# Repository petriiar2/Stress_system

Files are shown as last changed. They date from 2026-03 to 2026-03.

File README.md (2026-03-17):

# Physiological Monitoring System - Hardware Design & Sensor Integration

> **PCC1 Project | KTH Royal Institute of Technology | MSc Medical Engineering | Stockholm, 2026**  
> *This repository covers only the hardware design, sensor selection, wiring, and embedded firmware — the physical core of the system.*
> *Other aspects of the project ( software component , website ) not considered in this repository*

---

## Table of Contents

1. [Project Overview](#1-project-overview)
2. [System Architecture](#2-system-architecture)
3. [Internal Station — Patient Side](#3-internal-station--patient-side)
4. [External Station — Dentist Side](#4-external-station--dentist-side)
5. [Sensor Reference](#5-sensor-reference)
   - [Pressure Sensor](#51-pressure-sensor--abpdrrv060mgaa5)
   - [GSR Sensor](#52-gsr-sensor--galvanic-skin-response)
   - [Moisture Sensor](#53-moisture-sensor--adafruit-stemma)
   - [PPG Sensor](#54-ppg-sensor--max30102)
6. [Microcontrollers & Communication](#6-microcontrollers--communication)
7. [Power Supply](#7-power-supply)
8. [PCB](#8-pcb--enclosure)
9. [Current Limitations & Future Work](#9-current-limitations--future-work)
10. [Authorship & Contributions](#10-authorship--contributions)

---

## 1. Project Overview

Dental patients cannot speak during procedures. The traditional workaround — raising a hand to signal pain — forces dentists to split their attention between precise work under magnifying loupes and watching for a hand signal outside their field of view. It is also binary: the signal says *stop*, but conveys nothing about intensity or rising discomfort.

**BM-Dentist** is a Bluetooth-enabled physiological monitoring system that gives patients a richer, low-effort communication channel while providing dentists with objective, real-time data about patient comfort:

- A **squeeze ball** lets the patient signal pain by squeezing harder or with squeeze patterns (1 squeeze = mild, 2 = moderate, 3+ = severe).
- **Involuntary physiological sensors** (GSR + skin moisture) detect stress independently of the patient's conscious action — catching anxiety before it reaches the threshold of deliberate signalling.
- **LED ring indicators** on the dentist's side are positioned within their natural visual field and communicate pain and stress levels through colour and intensity without requiring the dentist to look away.
- A **web dashboard** logs all signals in real time and generates post-procedure statistics for quality improvement.

The system is designed as a prototype towards clinical use — not yet a certified medical device.

---

## 2. System Architecture

The system consists of three interconnected subsystems:

```
┌──────────────────────────────┐        BLE 5.0         ┌──────────────────────────────────────┐
│     INTERNAL STATION         │ ────────────────────►  │         EXTERNAL STATION             │
│        (Patient Side)        │                        │          (Dentist Side)              │
│                              │                        │                                      │
│  Pressure Sensor             │                        │  nRF52840 #1  ──UART──  nRF52840 #2  │
│  GSR Sensor                  │  XIAO nRF52840         │  LED Pain Ring          OLED Display │
│  Moisture Sensor             │  (BLE Peripheral)      │  LED Stress Ring        Buttons      │
│  MAX30102 (PPG)              │                        │  (BLE Central)          (BLE→USB)    │
│                              │                        │                                      │
└──────────────────────────────┘                        └──────────────┬───────────────────────┘
                                                                       │ USB Serial
                                                              ┌────────▼────────┐
                                                              │   WEB APP       │
                                                              │  (HTML/JS)      │
                                                              │  Real-time plot │
                                                              │  Post-proc stats│
                                                              └─────────────────┘
```

**Data flow summary:**

1. Sensors → Internal XIAO nRF52840 via analog ADC / I²C
2. Internal nRF → External nRF #1 via BLE UART (20 Hz)
3. External nRF #1 → LED rings (pain & stress visualisation) + External nRF #2 via UART
4. External nRF #2 → Computer via USB Serial → Web app

The web/software layer (dashboard, statistical analysis, CSV export) was developed by other team members and is referenced here for context only.

---

## 3. Internal Station — Patient Side

The internal station is the patient-held device. It houses all sensors, the microcontroller, and the BLE radio inside a custom 3D-printed enclosure designed for comfortable grip. Sensors that must contact the patient's skin (electrodes, moisture pad) exit the enclosure via JST connectors and are attached externally.

<p align="center">
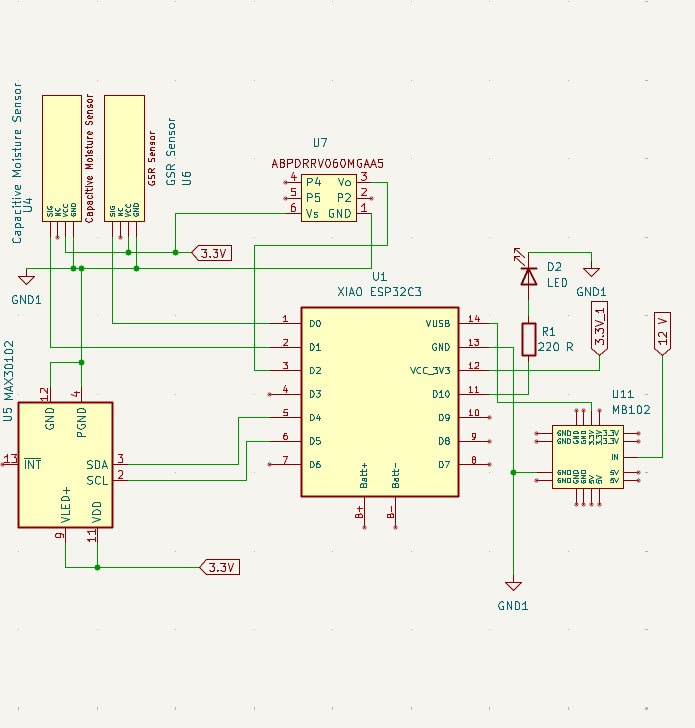
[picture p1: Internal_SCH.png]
  
  &nbsp;
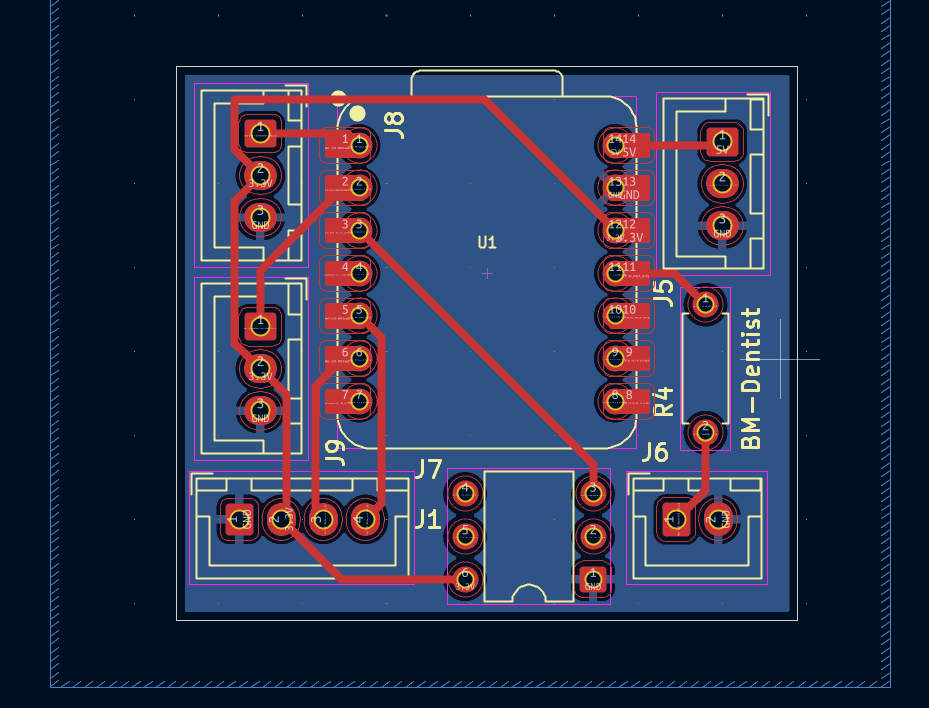
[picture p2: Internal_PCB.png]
  
</p>

<p align="center">
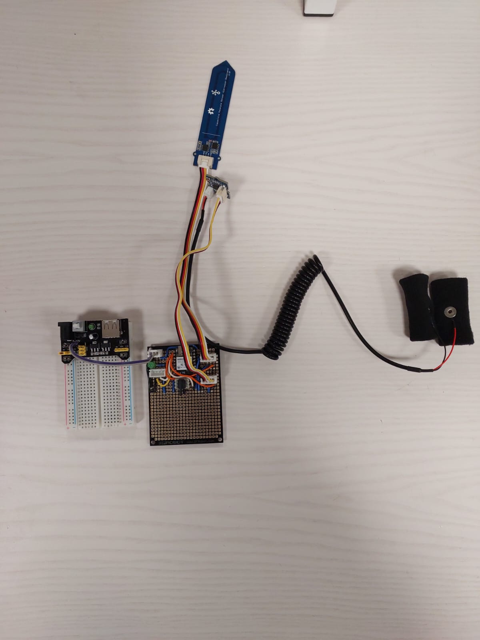
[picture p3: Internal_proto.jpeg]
  
</p>

### What it does

- Reads all four sensors at **20 Hz** via a continuous polling loop
- Packages readings into a CSV string: `pressure,gsr,moisture\n`
- Transmits over **BLE UART** to the external station
- Performs **min-max normalisation** against individually calibrated baseline values
- Drives a **status LED** (pin D10) to confirm active transmission

### Calibration

Before a procedure, a 5-second calibration sequence is triggered from the dentist side:

| Phase | Patient action | What is recorded |
|---|---|---|
| Resting | Hold balloon without squeezing | `P_min` — baseline pressure |
| Max squeeze | Squeeze as hard as possible | `P_max` — individual squeeze ceiling |
| Resting (continuous) | Stay relaxed | `GSR_baseline` — calm-state conductance average |

Subsequent readings are normalised as:

```
pressure_norm = (P_current - P_min) / (P_max - P_min)
stress_norm   = |GSR_current - GSR_baseline| / GSR_range
```

Patient gender and age category are also collected at calibration time (they affect pain thresholds), though in the current prototype the demographic adjustment coefficients are set to neutral (A=1.0, B=0.0) pending clinical data.

---

## 4. External Station — Dentist Side

The dentist-side station receives data wirelessly and translates it into immediate visual feedback — no screen-watching required.

<p align="center">
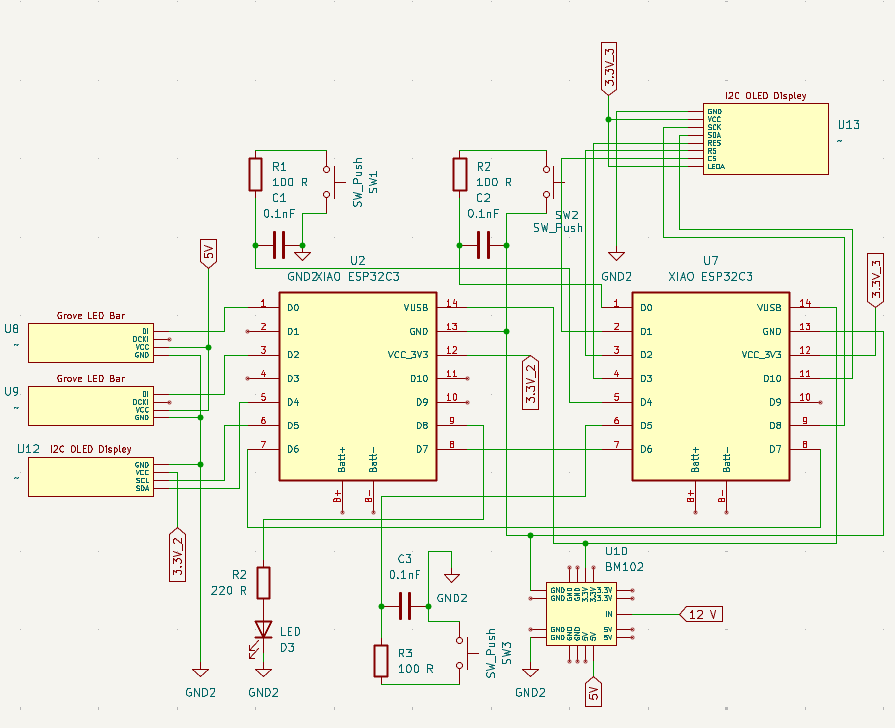
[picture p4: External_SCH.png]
  
  &nbsp;
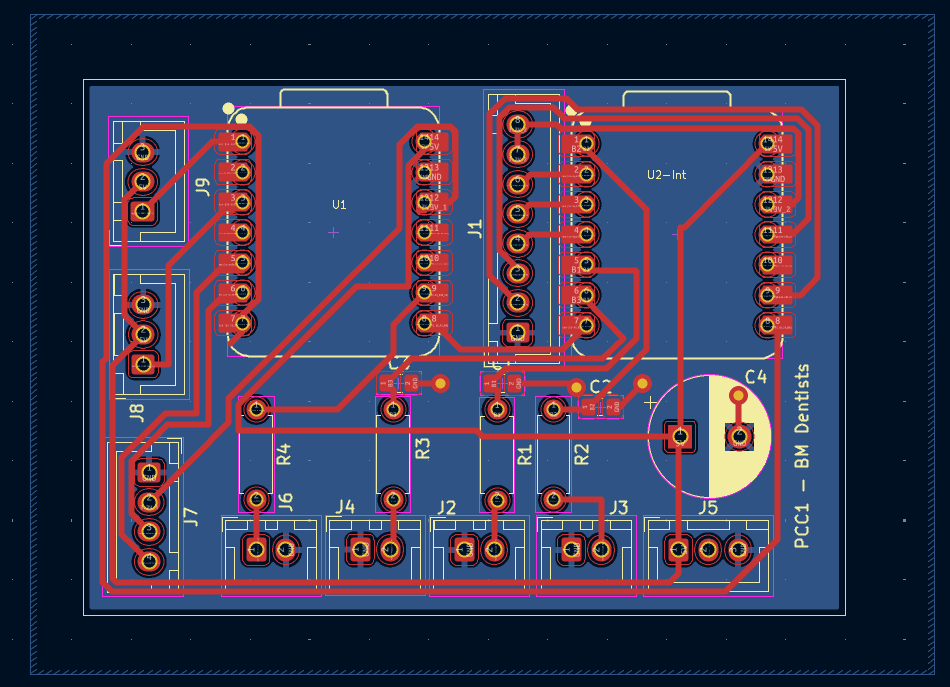
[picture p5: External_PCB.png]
  
</p>

<p align="center">
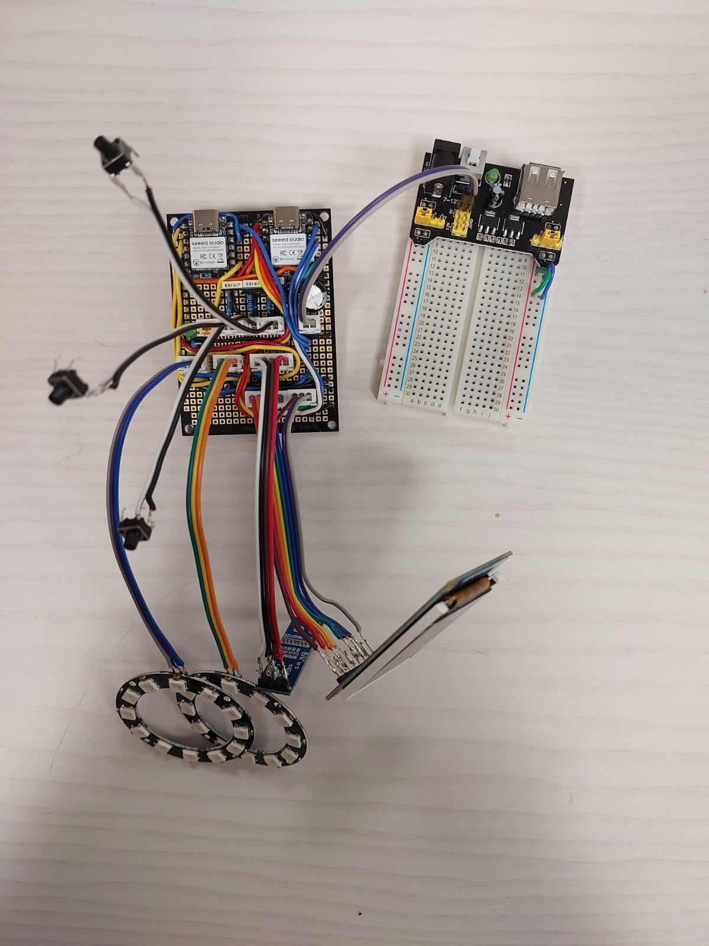
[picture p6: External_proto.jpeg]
  
</p>

### Dual-microcontroller architecture

Two XIAO nRF52840 boards are connected by a UART link (TX/RX crossed: D6↔D7):

**nRF52840 #1 — Signal processing & LED control**

- Acts as **BLE Central**: scans for and connects to the internal station (`"SensorNode"`)
- Parses the incoming CSV string and normalises sensor values
- Maps normalised pain to the number of illuminated LEDs on the **green pain ring**
- Maps normalised stress to the number of illuminated LEDs on the **blue stress ring**
- Flips stress ring colour to **red** when stress normalised value > 75% (urgent alert)
- Supports two pain-signalling modes (selectable at runtime):
  - **Direct mode**: squeeze force → proportional LED count
  - **Pattern mode**: counts squeeze edges in a sliding time window → 1 squeeze = few LEDs, 2 = moderate, 3+ = many
- Forwards raw data to nRF #2 via UART during working mode

**nRF52840 #2 — Interface & data relay**

- Drives the **OLED menu display** and three navigation buttons (Up / Down / Enter)
- Sends configuration commands to nRF #1:
  - `CALIB,<gender>,<age>` — start calibration
  - `RESET_CALIB` — wipe calibration
  - `WORKCFG` — start working mode with selected options
  - `WORK_END` — stop working mode, return to sleep
- Relays raw sensor data to the computer via BLE → USB Serial

### Operating modes

| Mode | Description |
|---|---|
| **Sleep** | BLE connection active, command exchange only — no data streaming or LED updates |
| **Working** | Full data streaming at 20 Hz, LED feedback active, data sent to computer |

---

## 5. Sensor Reference

### 5.1 Pressure Sensor — ABPDRRV060MGAA5

| Property | Value |
|---|---|
| Type | Analog MEMS pressure sensor |
| Interface | Analog voltage → ADC pin D2 |
| Supply | 3.3 V |
| ADC resolution | 12-bit (0–4095) |
| Physical connection | Flexible tubing → squeeze balloon (water bottle) |
| Sampling rate | 20 Hz |

**Purpose:** The primary intentional pain-signalling channel. The patient squeezes a balloon; the pressure sensor sits inside the enclosure connected by tubing, so there is no direct electronic contact with the patient's hand. This improves hygiene and allows the balloon to be replaced/sterilised between patients.

**What we get:** An analogue voltage proportional to balloon pressure. After calibration, this maps linearly to a 0–100% pain scale. In pattern mode, rising edges are counted over a sliding window to detect discrete squeeze events.

**Why this sensor:** The specific sensor was supplied to the team and is well-matched to the use case — it captures a deliberate, high signal-to-noise signal that requires no inference to interpret.

---

### 5.2 GSR Sensor — Galvanic Skin Response

| Property | Value |
|---|---|
| Type | Skin conductance, analog |
| Interface | Analog voltage → ADC pin D0 |
| Supply | 3.3 V |
| Electrode placement | Index finger + middle finger |
| Sampling rate | 20 Hz |

**Purpose:** Continuous, involuntary stress monitoring. Galvanic skin response measures changes in sweat gland activity driven by the sympathetic nervous system. It captures anticipatory anxiety — the patient may start showing stress before consciously deciding to squeeze.

**What we get:** A slow-varying analogue voltage that rises as skin conductance increases (higher stress → more perspiration → lower resistance → higher conductance). The deviation from the calibrated calm baseline is used as the stress metric.

**Why this sensor:** GSR is a well-established proxy for sympathetic arousal. Practical alternatives (e.g., dedicated EDA modules) had longer delivery times; the chosen module was available immediately and is straightforward to integrate with a single ADC pin.

**Wiring:** Two finger-clip electrodes connect to the sensor module via wires that exit the enclosure through a JST socket. The module output goes to pin D0.

---

### 5.3 Moisture Sensor — Adafruit STEMMA

| Property | Value |
|---|---|
| Type | Capacitive soil moisture sensor (repurposed) |
| Interface | Analog voltage → ADC pin D1 |
| Supply | 3.3 V |
| Placement | Palm contact (external, JST connector) |
| Sampling rate | 20 Hz |

**Purpose:** Secondary stress indicator via perspiration. Stress-induced sweating changes the dielectric properties of the skin surface, which the capacitive sensor detects as a change in output voltage.

**What we get:** An analogue voltage that varies with surface moisture. In our pilot validation, moisture features showed near-complete binary separation between no-stress and stress conditions (AUC ≈ 0.02–0.035, Cliff's δ ≈ −0.93 to −0.96 — moisture *decreases* in our sensor's output with higher sweat, reflecting sensor polarity).

**Important caveat:** This sensor is designed for soil, not human skin. Its readings are highly sensitive to contact area and the rigid structure makes consistent placement difficult. It is treated as an **exploratory channel** in the current prototype. A future iteration should replace it with a skin-validated conductance or hydration sensor.

**Wiring:** The sensor pad exits the enclosure via JST connector and is held against the patient's palm.

---

### 5.4 PPG Sensor — MAX30102

| Property | Value |
|---|---|
| Type | Photoplethysmographic (optical heart rate + SpO₂) |
| Interface | I²C → pins D4 (SDA) / D5 (SCL) |
| Supply | 3.3 V |
| Interrupt pin | D3 (INT, optional) |

**Purpose:** Heart rate and pulse-related metrics are strong indicators of physiological stress. HRV (heart rate variability) in particular is sensitive to autonomic nervous system state.

**Current status:** ⚠️ **Not used in the current validated prototype.** One of the two purchased modules was defective (internal short). The second produced unstable readings. The JST connector and I²C lines remain present on the PCB for future integration. Results in this report do not rely on PPG data.

**Why this sensor:** Selected primarily on cost, feature set, and community support under a limited budget. A future iteration should source a verified module or use an alternative such as the MAX86150.

---

## 6. Microcontrollers & Communication

### Seeed Studio XIAO nRF52840

Used for all three microcontroller roles (internal station + both external boards).

| Spec | Value |
|---|---|
| CPU | ARM Cortex-M4 @ 64 MHz |
| BLE | 5.0 integrated |
| ADC | 12-bit, 6 analog pins |
| Size | 20 × 17.5 mm |
| Supply | 3.3 V logic; powered via VBUS (5 V) |
| I²C | Hardware I²C on D4/D5 |
| UART | Hardware Serial1 on D6/D7 |

### BLE Configuration

- Internal board advertises as peripheral under name `"SensorNode"`
- External board #1 acts as central, scans and connects to `"SensorNode"`
- BLE UART service emulates serial over Bluetooth
- Data transmitted at 20 Hz; format: `"pressure,gsr,moisture\n"`
- ADC resolution set explicitly: `analogReadResolution(12)`

### UART Between External Boards

- Pins: `D6(#1) → D7(#2)`, `D7(#1) → D6(#2)` (TX/RX crossed)
- Baud rate: **115200**
- Commands flow #2 → #1; raw data flows #1 → #2
- In sleep mode: command exchange only. In working mode: full 20 Hz data stream.

---

## 7. Power Supply

### MB102 Breadboard Power Module

Used on both internal and external stations.

| Output | Used for |
|---|---|
| 5 V | XIAO VBUS pin, LED rings (5 V NeoPixel-type) |
| 3.3 V | All sensors (pressure, GSR, moisture, PPG) |

- Each XIAO board provides its own 3.3 V rail from its onboard regulator — two separate 3.3 V rails on the external station to distribute load.
- All boards and sensors share a **common ground**.
- MB102 includes overcharge/overdischarge protection.

---

## 8. PCB 

### PCB Design

Schematics and PCB layouts were designed in **KiCad**. Key design decisions:

- **JST connectors** used extensively throughout — sensors on the internal board and interface elements on the external board are all physically external to the PCB, so connectors allow clean cable management and easy swapping.
- PCB fabrication within university facilities was not feasible in the project timeline, so components were soldered onto **prototyping (perfboard) boards** following the KiCad layout.

KiCad project files are included in `/internal/` or `/external/` .

---

## 9. Current Limitations & Future Work

| Area | Current state | Planned improvement |
|---|---|---|
| PPG (heart rate) | Unstable — excluded from prototype | Source verified MAX30102 or MAX86150; repeat validation |
| Moisture sensor | Exploratory — not skin-specific | Replace with validated skin conductance/hydration sensor |
| Demographic calibration | Coefficients set to neutral (A=1, B=0) | Add clinically derived thresholds per gender/age group |
| Clinical validation | Simulated stress (video induction), 1 subject | Ethically approved trials with real dental patients |
| Enclosure | Internal box only printed | Print external box; ergonomic redesign for sterile grip |
| Accessibility | Hand squeeze only | Add foot-operated or capacitive-touch alternative inputs |
| Sterilisation | Not yet validated | Material selection and sterilisation protocol testing |

---

## 10. Authorship & Contributions

The hardware design presented in this repository — including sensor selection and wiring,
PCB schematics, microcontroller configuration, BLE/UART communication
architecture, and embedded firmware for data acquisition and LED control — was designed
and implemented by **Iaroslav Petrishchev**.

The following parts of the system are the work of other team members and are therefore
not covered in this repository:

- **Web application & real-time dashboard** (HTML/JS, Chart.js, Web Serial API) — *Naya Nasr & Yanzi Yu*
- **Post-procedure statistical analysis & CSV export** — *Naya Nasr & Yanzi Yu*
- **Clinical research, sensor rationale & validation study** — *Naya Nasr & Yanzi Yu*

> Full project report available upon request.

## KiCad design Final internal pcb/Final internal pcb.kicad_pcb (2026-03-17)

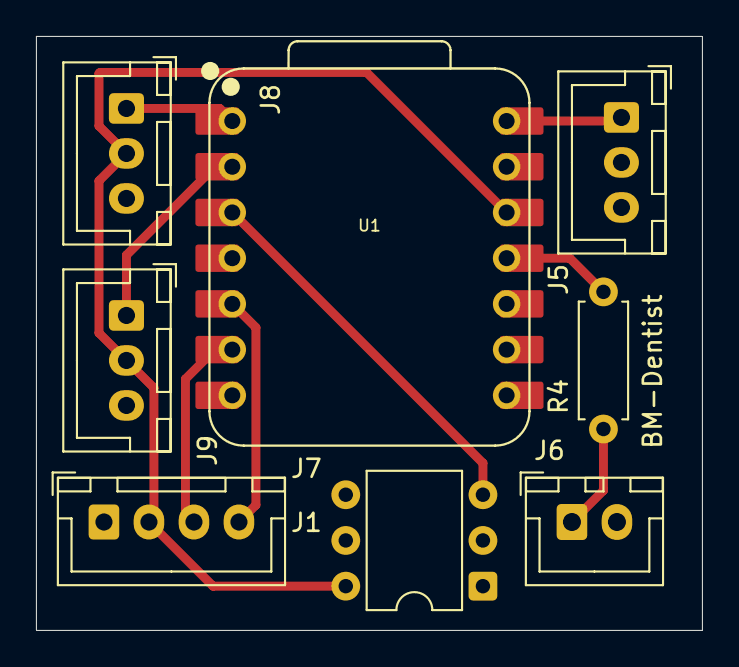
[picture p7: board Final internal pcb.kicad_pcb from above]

Board: 2 copper layers, 37.0 x 33.0 mm, 8 parts (0 on the bottom side), 10 nets.

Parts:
J1: Conn_01x06; DIP-6_W7.62mm
J5, J8, J9: Conn_01x03_Socket; JST_XH_B3B-XH-A_1x03_P2.50mm_Vertical
J6: Conn_01x02_Socket; JST_XH_B2B-XH-A_1x02_P2.50mm_Vertical
J7: Conn_01x04_Socket; JST_XH_B4B-XH-A_1x04_P2.50mm_Vertical
R4: 220 R; R_Axial_DIN0207_L6.3mm_D2.5mm_P7.62mm_Horizontal
U1: XIAO-nRF52840-DIP

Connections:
3.3V: J1.6, J7.2, J8.2, J9.2, U1.12 (3V3)
5V: J5.1, U1.14 (VBUS)
GND: J1.1, J5.3, J6.2, J7.1, J8.3, J9.3, U1.13 (GND)
unnamed: J1.3, U1.3 (P0.28_AIN4_LOW_A2_D2)
unnamed: J6.1, R4.2
unnamed: J7.3, U1.6 (P0.05_AIN3_A5_D5)
unnamed: J7.4, U1.5 (P0.04_AIN2_A4_D4)
unnamed: J8.1, U1.1 (P0.02_AIN0_LOW_A0_D0)
unnamed: J9.1, U1.2 (P0.03_AIN1_LOW_A1_D1)
unnamed: R4.1, U1.11 (P1.15_MOSI_D10)

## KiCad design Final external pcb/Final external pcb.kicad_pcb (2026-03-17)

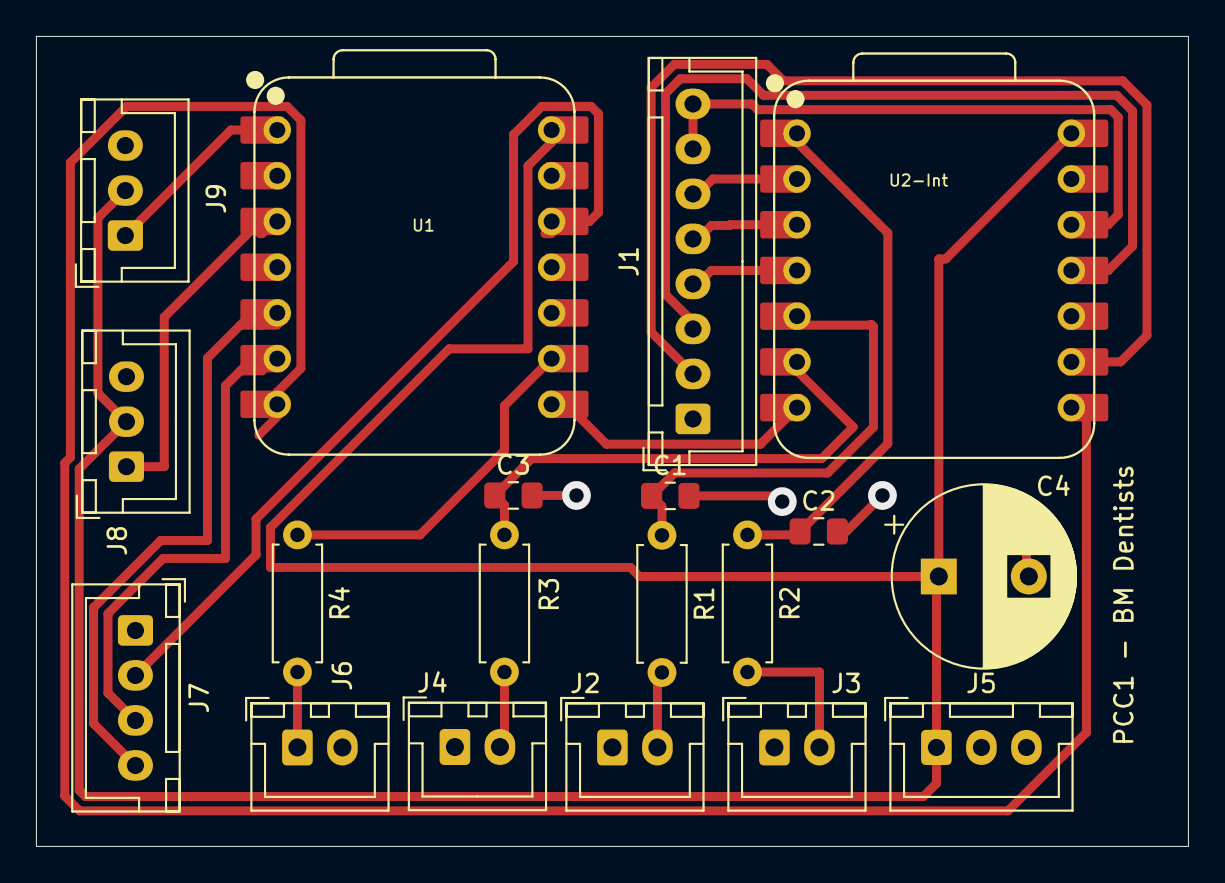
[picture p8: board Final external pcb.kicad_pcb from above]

Board: 2 copper layers, 64.0 x 45.0 mm, 19 parts (0 on the bottom side), 23 nets.

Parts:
C1, C2, C3: 0.1 nF; C_0805_2012Metric_Pad1.18x1.45mm_HandSolder
C4: 1000uF; CP_Radial_D10.0mm_P5.00mm
J1: Conn_01x08_Socket; JST_XH_B8B-XH-A_1x08_P2.50mm_Vertical
J2, J3, J4, J6: Conn_01x02_Socket; JST_XH_B2B-XH-A_1x02_P2.50mm_Vertical
J5, J8, J9: Conn_01x03_Socket; JST_XH_B3B-XH-A_1x03_P2.50mm_Vertical
J7: Conn_01x04_Socket; JST_XH_B4B-XH-A_1x04_P2.50mm_Vertical
R1, R2, R3: 10k R; R_Axial_DIN0207_L6.3mm_D2.5mm_P7.62mm_Horizontal
R4: 220 R; R_Axial_DIN0207_L6.3mm_D2.5mm_P7.62mm_Horizontal
U1, U2-Int: XIAO-nRF52840-DIP

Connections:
3.3V_1: J7.2, U1.12 (3V3)
3.3V_2: J1.7, J1.8, U2-Int.12 (3V3)
5V: C4.1, J5.1, J8.2, J9.2, U1.14 (VBUS), U2-Int.14 (VBUS)
B1: C1.1, R1.1, U2-Int.5 (P0.04_AIN2_A4_D4)
B2: C2.1, R2.1, U2-Int.1 (P0.02_AIN0_LOW_A0_D0)
B3: C3.1, R3.1, U2-Int.6 (P0.05_AIN3_A5_D5)
GND: C1.2, C2.2, C3.2, C4.2, J1.1, J2.1, J3.1, J4.1, J5.3, J6.2, J7.1, J8.3, J9.3, U1.13 (GND), U2-Int.13 (GND)
unnamed: J1.2, U2-Int.9 (P1.13_SCK_D8)
unnamed: J1.3, U2-Int.11 (P1.15_MOSI_D10)
unnamed: J1.4, U2-Int.4 (P0.29_AIN5_LOW_A3_D3)
unnamed: J1.5, U2-Int.3 (P0.28_AIN4_LOW_A2_D2)
unnamed: J1.6, U2-Int.2 (P0.03_AIN1_LOW_A1_D1)
unnamed: J2.2, R1.2
unnamed: J3.2, R2.2
unnamed: J4.2, R3.2
unnamed: J6.1, R4.2
unnamed: J7.3, U1.6 (P0.05_AIN3_A5_D5)
unnamed: J7.4, U1.5 (P0.04_AIN2_A4_D4)
unnamed: J8.1, U1.3 (P0.28_AIN4_LOW_A2_D2)
unnamed: J9.1, U1.1 (P0.02_AIN0_LOW_A0_D0)
unnamed: U1.7 (P1.11_TX_D6), U2-Int.8 (P1.12_RX_D7)
unnamed: U1.8 (P1.12_RX_D7), U2-Int.7 (P1.11_TX_D6)
unnamed: R4.1, U1.9 (P1.13_SCK_D8)

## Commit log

2026-03-17 Revise PCB section and remove enclosure content
    Updated PCB section and removed enclosure details.
2026-03-17 Update README with prototype images and descriptions
    Added images and updated descriptions for internal and external prototypes.
2026-03-17 External_part files
    [Final external pcb-B_Cu.gbr, Final external pcb-B_Paste.gbr, Final external pcb-B_Silkscreen.gbr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]
